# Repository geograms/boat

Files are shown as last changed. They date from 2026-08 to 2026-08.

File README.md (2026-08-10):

# Boat-Home — Road-Towable Solar Trimaran

A 7.2 m Dutch-barge-style boat-home that is **its own trailer**: the
stabiliser floats fold underneath the hull and carry six driven wheels,
so one Mercedes-Viano-class car tows it on German roads and it drives
itself in and out of the water on a slipway. Solar-electric, weed-proof
waterjets, and a walk-on glass sun deck — you stand on the glass, the
panels live safely underneath it.

Parametric CAD in FreeCAD (Python-scripted); every legal, structural
and hydrostatic constraint is asserted in code, so a dimension cannot
drift without the build failing.

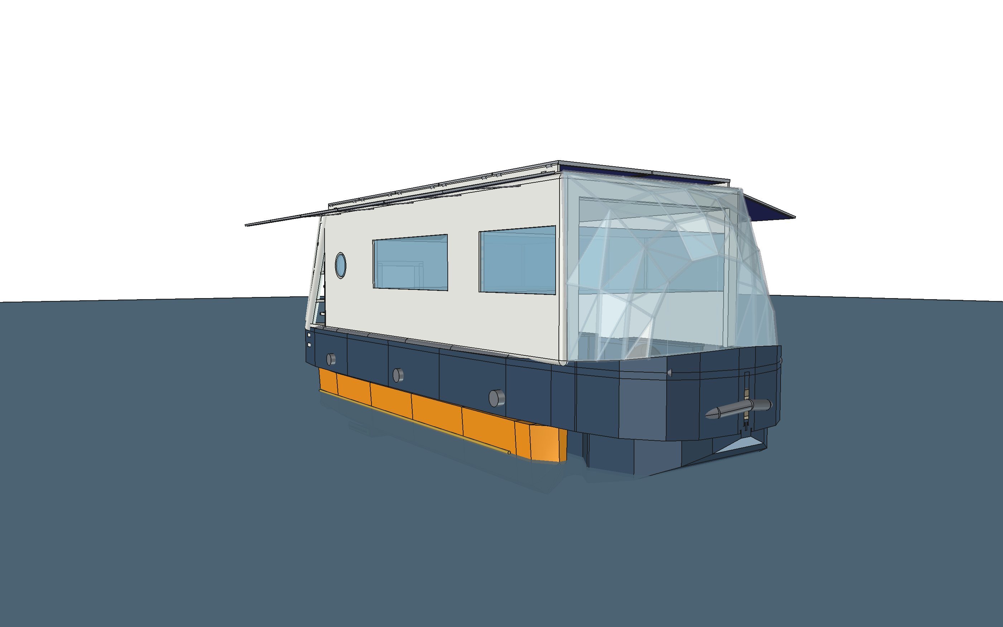
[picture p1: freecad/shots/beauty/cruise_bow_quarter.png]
cruise


---

## 1. Principal dimensions

| | |
|---|---|
| Length over hull | **7 200 mm** |
| Length with drawbar out | **9 094 mm** |
| Beam, hull | **2 500 mm** |
| Beam, road (folded) | **2 535 mm** (StVZO limit 2 550) |
| Beam, afloat (floats out) | **4 716 mm** |
| Height on the road | **3 002 mm** (limit 4 000) |
| Air draft afloat | **2 260 mm** |
| Draft | **279 mm** empty, **299 mm** loaded (hull carries the boat only) |
| Freeboard, loaded | 851 mm |
| Mass, boat alone | **2 228 kg** empty (the hangar floats itself) |
| Mass, hangar | **901 kg** — a complete trailer |
| Mass, combination | **3 429 kg** with crew and stores |
| Road category | **O2 trailer, ≤ 3 500 kg** — 252 kg of margin loaded |
| Ground clearance, road | 482 mm |
| Track / wheelbase | 1 820 / 3 300 mm |
| Coupling height / tongue load | 445 mm / +100 kg |

### Living quarters

| | |
|---|---|
| Cabin | 5 300 × 2 280 mm inside |
| Headroom | **1 850 mm** clear over the sole |
| Floor area | 12.1 m² |
| Berths | **5** — athwartships double, bunk (2), single settee, dinette double |
| Heads | 1 400 × 900 wetroom with shower |
| Galley | induction hob, sink, washer-dryer, full-height fridge/freezer |
| Fresh water | 200 L in a bilge tank under the sole |
| Glazing | 2 picture windows per side, 1 800 × 600 and 1 200 × 600 |
| Sky dome | glass room forward, **no wall** — 2 040 mm portal, sole continuous, 2 050 mm head |

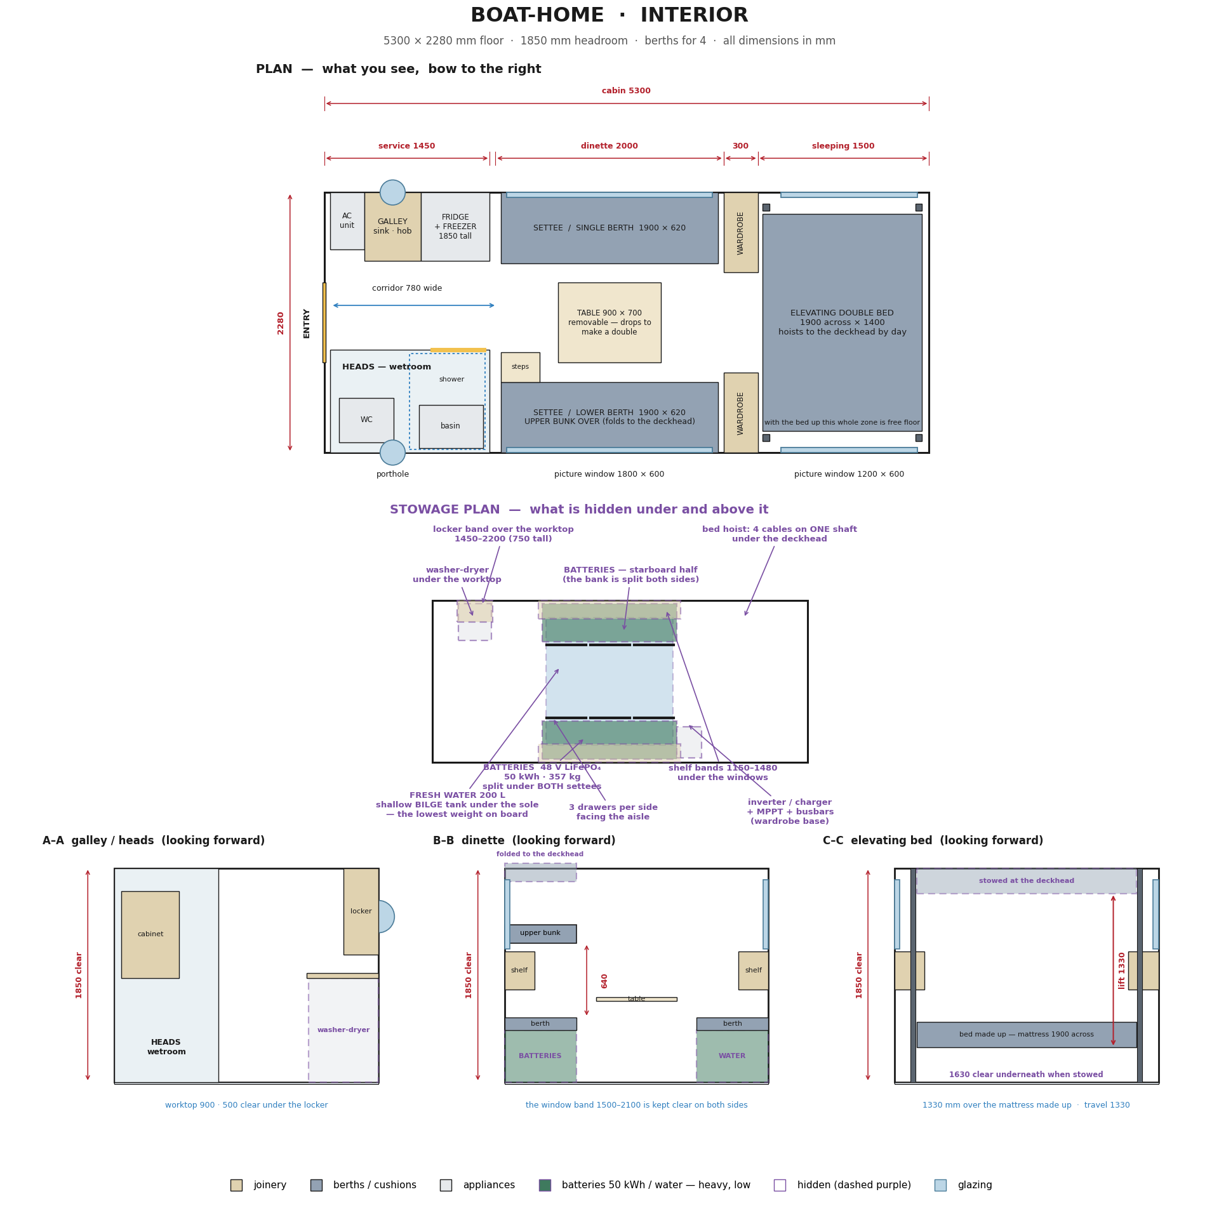
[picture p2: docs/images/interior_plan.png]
interior


---

## 2. Performance

**Installed power: 3 × 2 kW flush-intake waterjets = 6 kW.** Estimates
from an ITTC friction line plus a residuary factor for a blunt barge
hull; wetted surface 28.0 m² in trimaran trim, **3 582 kg all-up — the
computed mass, wired to `params.mass_budget()`**, waterjet propulsive
efficiency 0.45. Method in
[docs/performance.md](docs/performance.md).

| Speed | Shaft power | Range on 45 kWh usable | Endurance |
|---|---|---|---|
| 2.0 kn | 0.18 kW | **488 NM** | 244 h |
| 3.0 kn | 0.58 kW | **233 NM** | 78 h |
| 3.5 kn | 1.03 kW | **153 NM** | 44 h |
| 4.0 kn | 2.15 kW | **84 NM** | 21 h |
| 4.5 kn | 4.37 kW | **46 NM** | 10 h |
| **4.7 kn max** | 6.0 kW | 32 NM | 7 h |

**Maximum ≈ 4.7 knots**, power-limited rather than hull-speed-limited
(theoretical hull speed is 6.2 kn, needing 30 kW). The last 0.2 kn costs as much power
as the first 4 — this is a boat to cruise at 3–4 kn, not to push.

**Solar-neutral cruising.** With 4.60 kWp and ≈ 24 kWh on a good summer
day, eight hours at **4.2 knots** is solar-neutral: the boat moves all day
and finishes with a fuller battery than it started. In spring or autumn
(12 kWh) that falls to 3.6 kn, and on an overcast winter day (6 kWh) to
2.7 kn.

| | |
|---|---|
| Battery | 48 V LiFePO₄, **50 kWh**, 357 kg, split under both settees |
| Structure | foam-core GRP sandwich, 103 m² of panel, **754 kg** |
| Solar | **4.60 kWp** — 10 × 230 W flexible on the roof, 10 more as side curtains (4.14 kWp effective; one panel type for the whole boat) |
| House load | ≈ 2.5 kWh/day (fridge, lights, water, AC standby) |
| Steering | differential thrust, no rudder |
| On land | ≤ 10 km/h under its own wheels; towed at road speeds |

---

## 3. The five configurations

Photo-reference renders — perspective camera, natural eye heights,
interior hidden and glazing closed so nothing reads as a cutaway — live
in `freecad/shots/beauty/`: five viewpoints per mode (bow quarter,
stern quarter, beam on, from above, low from the water), 2 800 × 1 750.
They are the plates at the front of the PDF gallery.

| Mode | What it is | Renders |
|---|---|---|
| `road` | floats folded under the hull, balconies up over the windows, towed stern-first | [bow qtr](freecad/shots/beauty/road_bow_quarter.png) · [stern qtr](freecad/shots/beauty/road_stern_quarter.png) · [beam](freecad/shots/beauty/road_beam.png) · [above](freecad/shots/beauty/road_drone.png) · [low](freecad/shots/beauty/road_low.png) |
| `launch` | driving itself down the slipway on six wheels | [bow qtr](freecad/shots/beauty/launch_bow_quarter.png) · [stern qtr](freecad/shots/beauty/launch_stern_quarter.png) · [beam](freecad/shots/beauty/launch_beam.png) · [above](freecad/shots/beauty/launch_drone.png) · [low](freecad/shots/beauty/launch_low.png) |
| `harbor` | jack-up: floats carry the boat, keel awash, tyres as rolling quay fenders | [bow qtr](freecad/shots/beauty/harbor_bow_quarter.png) · [stern qtr](freecad/shots/beauty/harbor_stern_quarter.png) · [beam](freecad/shots/beauty/harbor_beam.png) · [above](freecad/shots/beauty/harbor_drone.png) · [low](freecad/shots/beauty/harbor_low.png) |
| `cruise` | trimaran, floats out, balconies down | [bow qtr](freecad/shots/beauty/cruise_bow_quarter.png) · [stern qtr](freecad/shots/beauty/cruise_stern_quarter.png) · [beam](freecad/shots/beauty/cruise_beam.png) · [above](freecad/shots/beauty/cruise_drone.png) · [low](freecad/shots/beauty/cruise_low.png) |
| `anchor` | at anchor, held by the stern anchor | [bow qtr](freecad/shots/beauty/anchor_bow_quarter.png) · [stern qtr](freecad/shots/beauty/anchor_stern_quarter.png) · [beam](freecad/shots/beauty/anchor_beam.png) · [above](freecad/shots/beauty/anchor_drone.png) · [low](freecad/shots/beauty/anchor_low.png) |

cruise, bow quarter

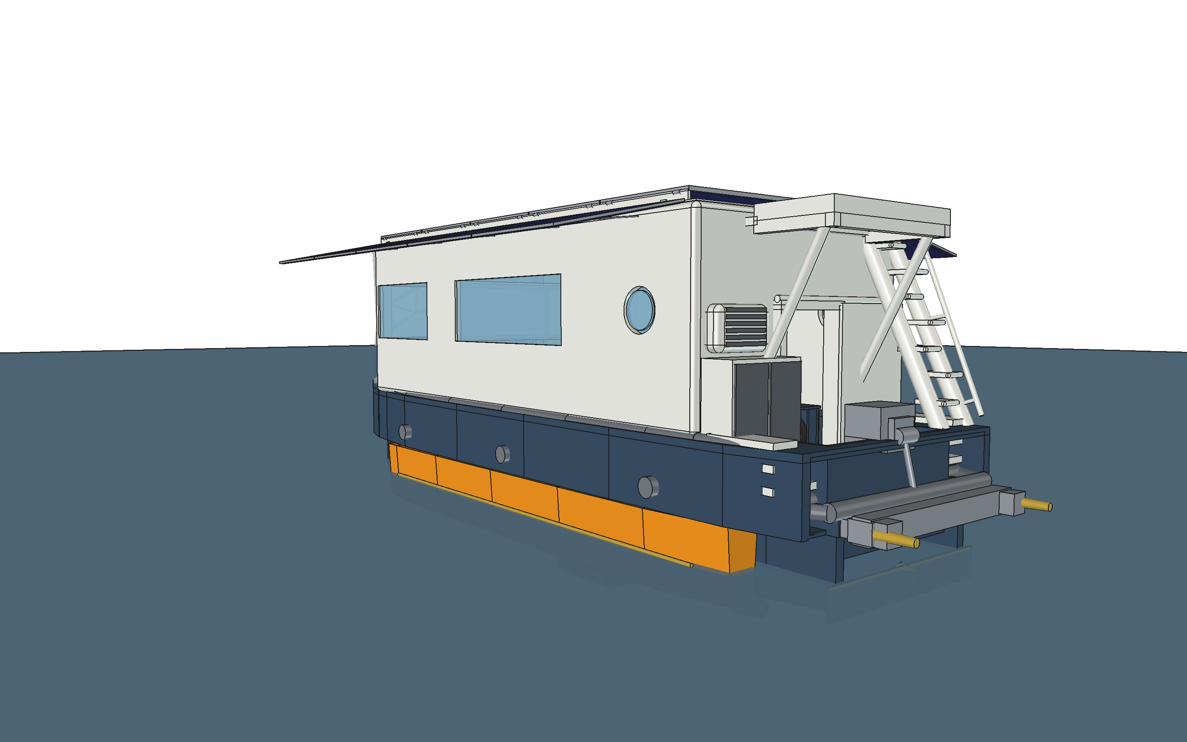
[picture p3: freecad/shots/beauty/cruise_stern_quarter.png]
cruise, stern quarter


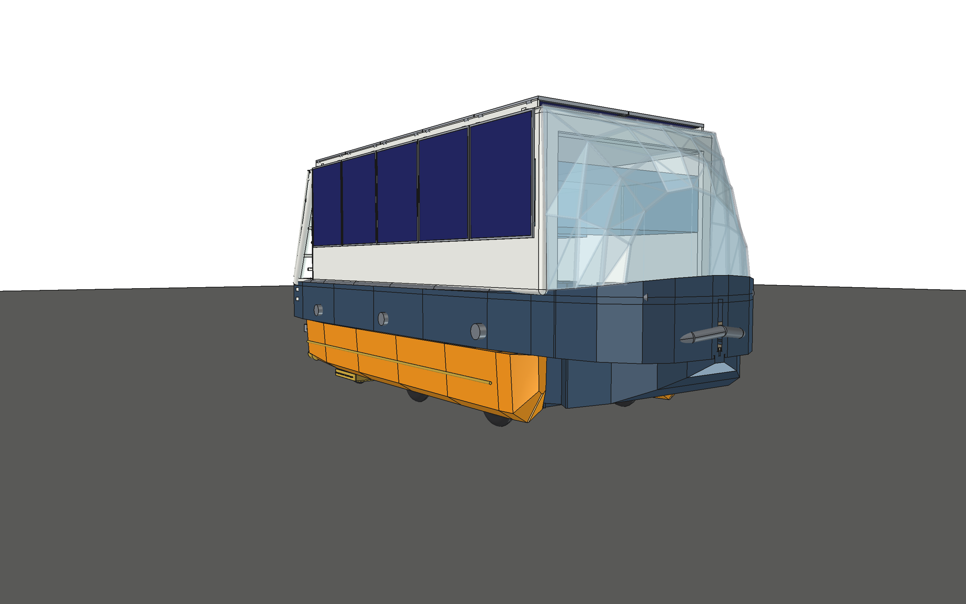
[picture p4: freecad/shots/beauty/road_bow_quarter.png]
road, bow quarter


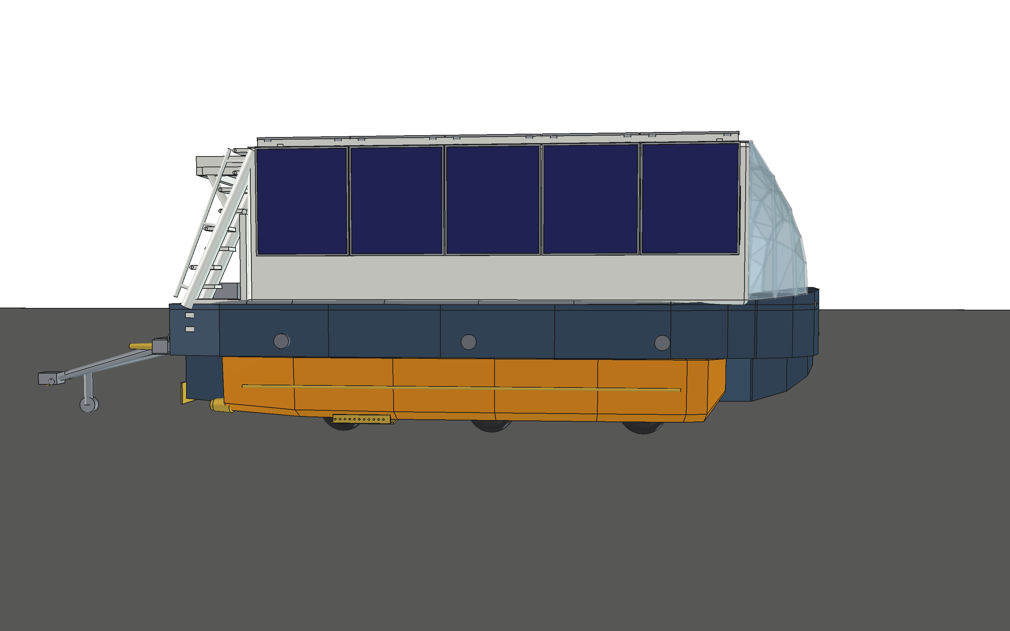
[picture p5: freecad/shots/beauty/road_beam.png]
road, beam on


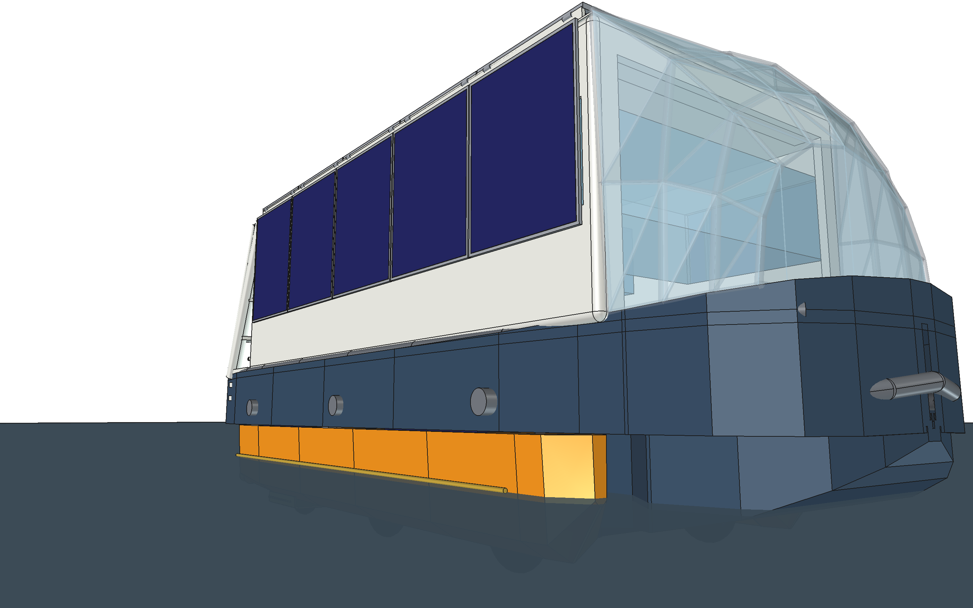
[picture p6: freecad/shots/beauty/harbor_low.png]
harbour, low from the water


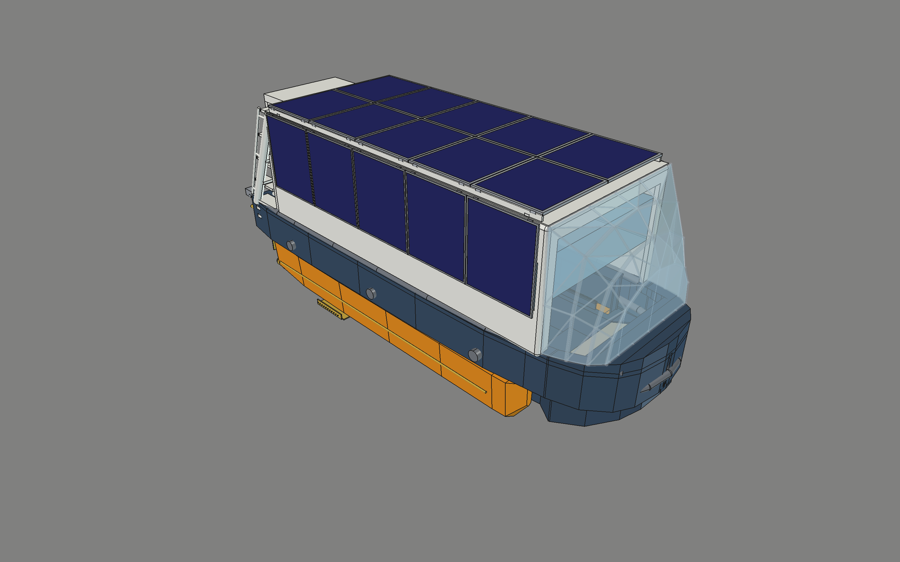
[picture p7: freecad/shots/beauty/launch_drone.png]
launch, from above


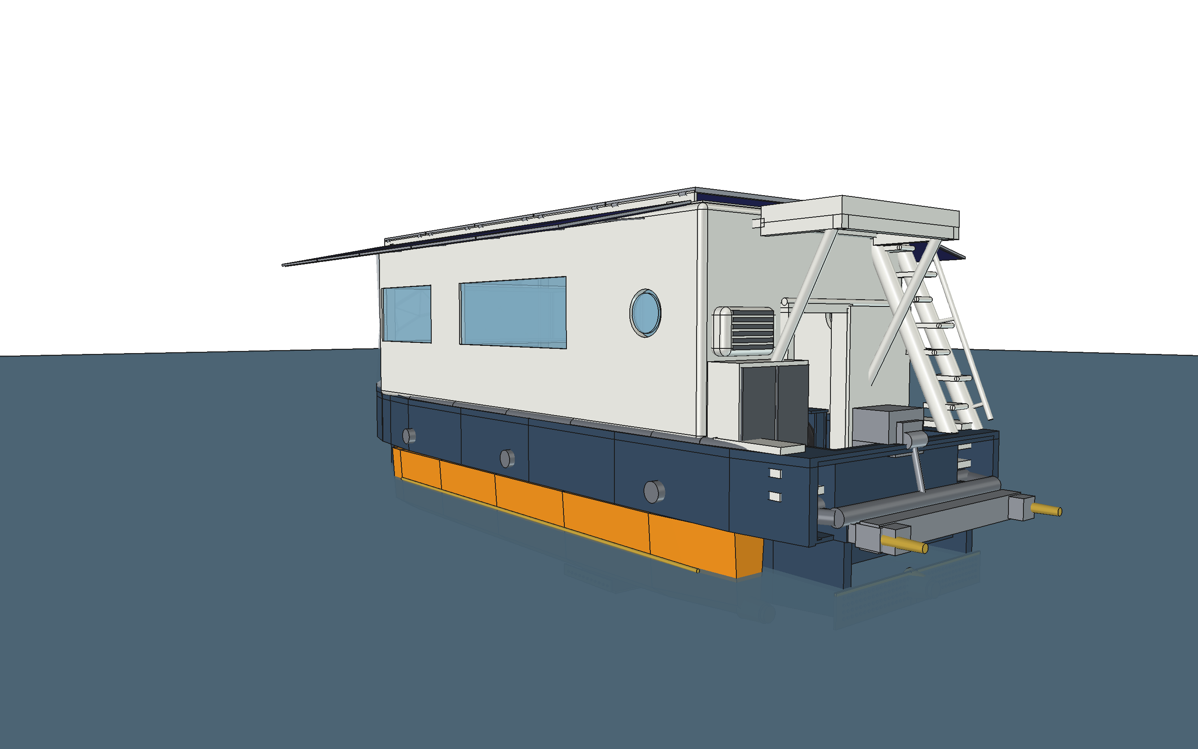
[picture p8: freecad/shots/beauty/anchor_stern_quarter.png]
anchor, stern quarter


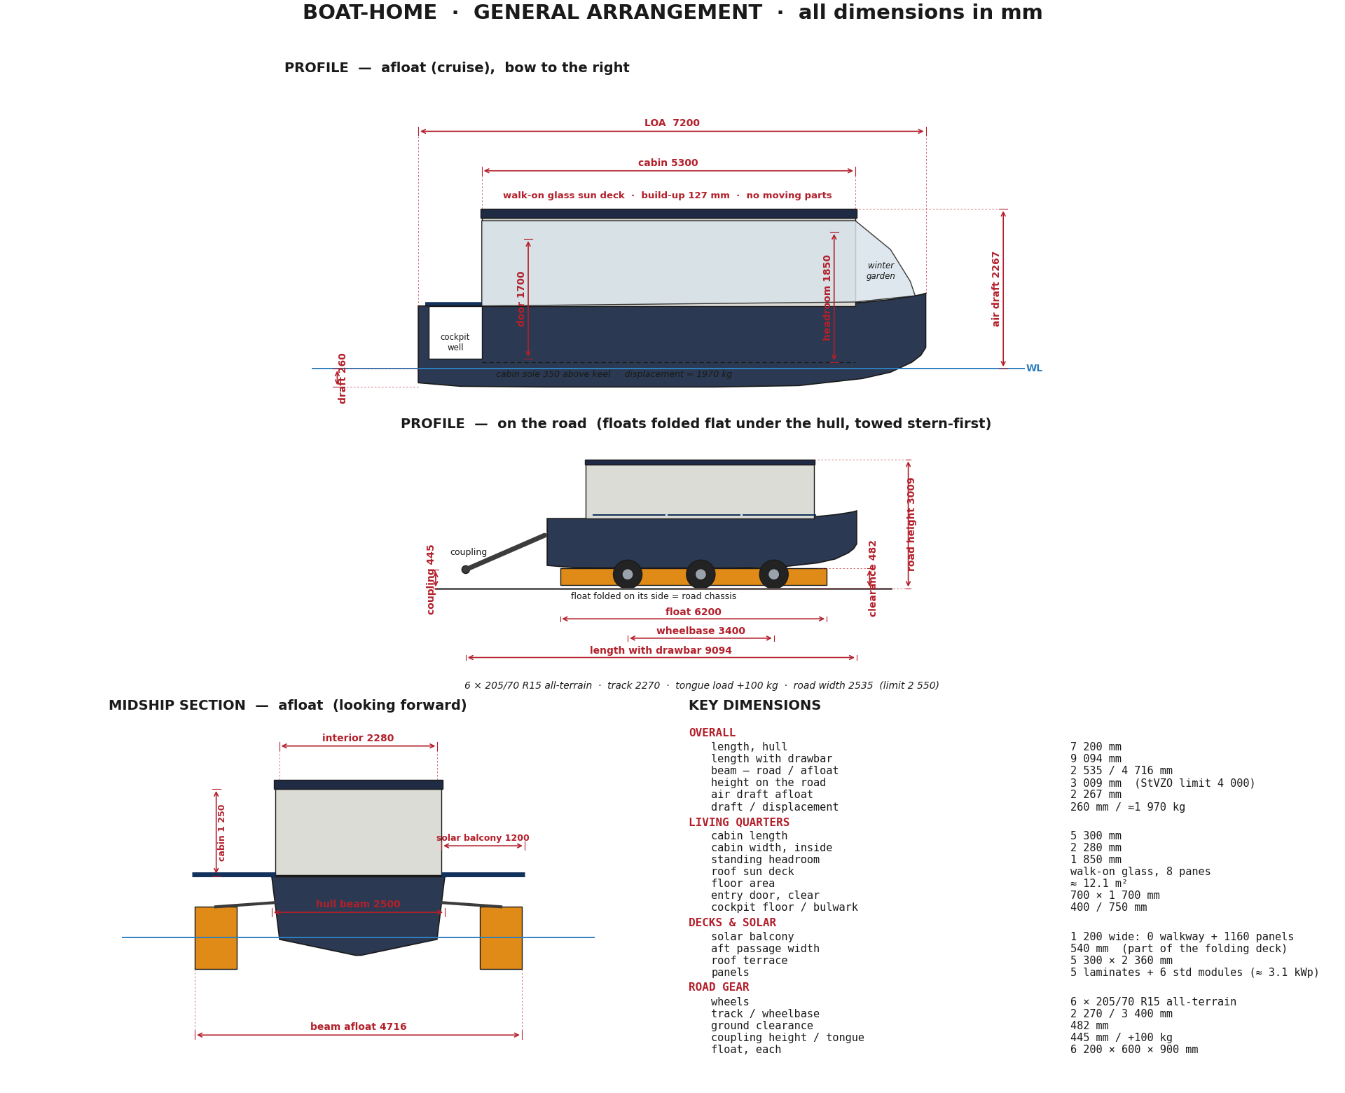
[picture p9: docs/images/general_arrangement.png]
general arrangement


---

## 4. Key systems

**Detachable hangar** — the running gear is a **separate vehicle**: two
spine beams along the hull sides carrying the four arm shoulders, joined
aft of the transom by a bight that carries the drawbar. It couples on the
water — cone guides, then four 24 V worm bayonet locks — and detached it
is a **4.7 m catamaran dinghy** with a motor in each float. The point is
certification: the hangar is the trailer, **the boat is cargo**.
→ [docs/hangar.md](docs/hangar.md)

**Running gear** — one rigid welded arm per station, a single
shoulder pin, 90° swing. Road: float on its side flush under the hull,
wheels vertical. Water: float flat, wheels dry above the waterline. Six
155/70 R12C trailer wheels on swing arms, electric-over-hydraulic drive with the
machinery sealed inside the floats. → [docs/wheels.md](docs/wheels.md)

**Stability** — the stem alone has **GM −0.43 m**: the floats are not a
stability aid, they *are* the stability. Extending them takes GM from
1.20 to **4.59 m** and peak righting from 3.8 to **14.8 kNm** — nearly
**4 ×** — and beam from 2.48 to **4.02 m**. The curve peaks at 16° and
saturates there: the float has 205 mm of freeboard. What actually
limits the boat in a blow is windage, not the floats: stand the solar
rails up in a Beaufort 6 gust and the margin falls to 1.12.
→ [docs/stability.md](docs/stability.md)

**Propulsion** — flush perforated intake grids on the float sides below
the waterline (0.5 m/s face velocity, 14 mm holes, so weed drifts past),
internal duct to an enclosed pump, tail nozzle. Nothing rotating is
reachable by weed. → [docs/propulsion.md](docs/propulsion.md)

**Exoskeleton** — an external steel ladder-loop frame carries every
point load (arms, balconies, tow, fenders); nothing structural crosses
the living volume. → [docs/structure.md](docs/structure.md)

**Construction** — primary structure is **foam-core GRP sandwich**: PVC
and PET core, biaxial E-glass skins, epoxy, vacuum bagged, panels laid
up flat on a table and CNC-cut from the model. **103 m² of panel,
754 kg** — computed from measured areas × the laminate schedule, not
estimated. The middle 3.6 m of the hull is exactly developable, so it
needs no jig at all. → [docs/construction.md](docs/construction.md)

**Roof deck** — the solar panels **are** the guardrail. Two continuous
rows of five 230 W flexible laminates in alu frames hinge on the deck
edges: flat they cover the roof and harvest **2.30 kWp**, rotated up
they stand as a **1 234 mm barrier** and leave the whole 12.7 m² deck
free to walk on. No glass, one hinge and one catch per panel. It
replaced a walk-on glass deck that weighed 460 kg with **155 kg** — and
that deck had no guardrail at all.
→ [docs/roof.md](docs/roof.md)

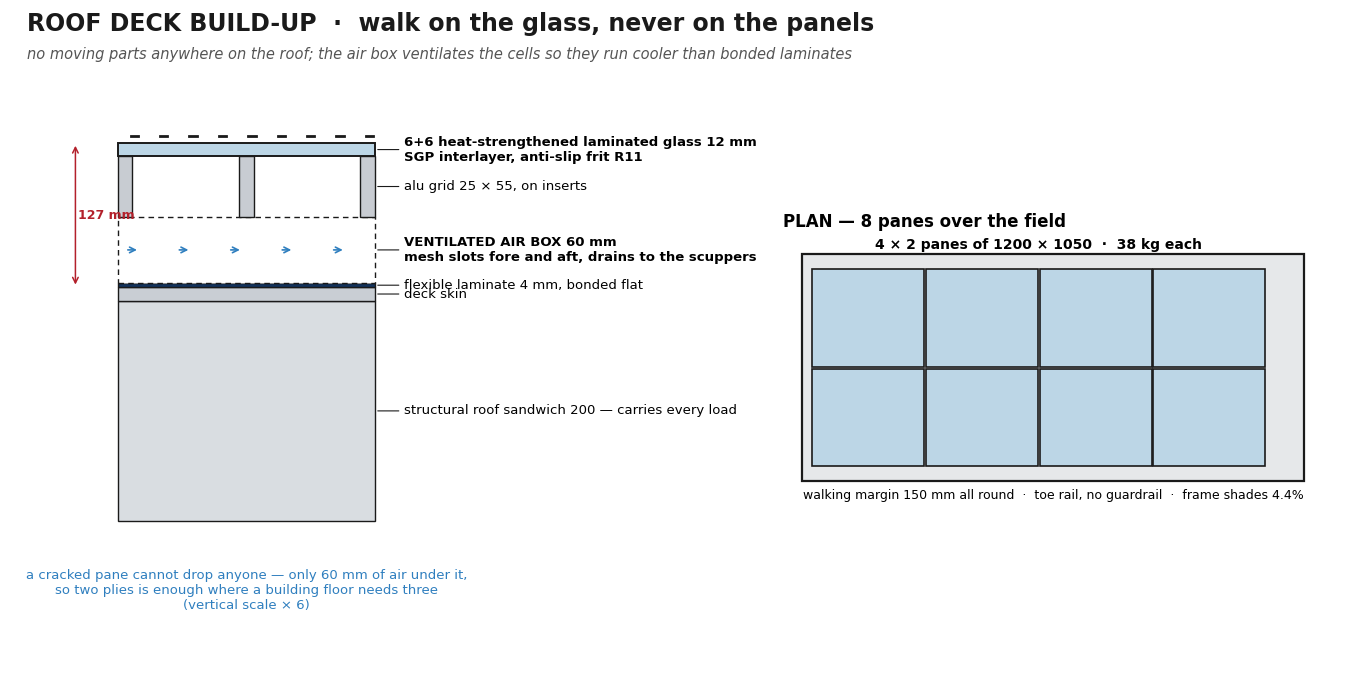
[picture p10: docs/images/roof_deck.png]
roof deck


**Solar curtains** — the balconies are gone. The same panel as the roof
rails, five a side, hinged on the roof-to-wall corner: closed they cover
the windows and slim the boat for the road, at 78° they project 1 129 mm
out as an awning over the glass. 2.30 kWp for **117 kg**, where the
walkable balconies were ~298 kg of frame and mechanism.
→ [docs/roof.md](docs/roof.md)

**Interior** — heads, galley, dinette that sleeps two, elevating double
bed forward, fold-down bunk to port; batteries and water low and
amidships. → [docs/interior.md](docs/interior.md)

**Front sky dome** — a glazed conservatory over the foredeck: half a
dome cut flat by the deck, so the deck is its floor and you walk into
it from the saloon — **no wall**, a 2 040 mm portal and the sole runs
straight through, 2 050 mm of headroom. Its aft rim lands exactly on
the living-quarters box corners. **51 flat panes**, all flat to
0.00 mm, on 8 meridians and **two ⌀48 tube purlins**: flat glass means
any pane can be re-cut anywhere.
→ [docs/dome.md](docs/dome.md)

**Tow and stern gear** — a wide A-arch on the transom pin-locks into a
sea gantry or an extensible drawbar; the 2 t electric self-recovery
winch and the anchor share the centreline so a ramp pull has no yaw
bias.

---

## 5. Cost estimate (2026, EUR, materials)

| Item | Low | High | Source |
|---|---|---|---|
| Foam core, PVC + PET, by zone | 3 800 | 5 200 | [hangar.md](docs/hangar.md) | detachable U-frame: coupling, electric locks, dinghy mode |
| [construction.md](docs/construction.md) |
| Glass fabric, biax NCF, roll quantities | 2 200 | 3 000 | 203 kg dry |
| Epoxy resin, hardener, fillers | 4 500 | 6 500 | 248 kg mixed |
| Vacuum consumables | 1 200 | 2 000 | €10–20/m² per shot |
| Fairing compound, primer | 900 | 1 500 | 400 h of it |
| Tooling: pump, table, extraction, PPE | 1 500 | 2 500 | one-off |
| Exoskeleton frame + tow arch | 2 600 | 3 200 | [structure.md](docs/structure.md) |
| Wheels, hubs, in-float drive | 5 600 | 6 500 | [wheels.md](docs/wheels.md) |
| Propulsion, 3 × 2 kW waterjets | 8 800 | 13 300 | [propulsion.md](docs/propulsion.md) |
| Roof deck: 10 flexible panels, alu frames, hinges | 2 900 | 3 400 | [roof.md](docs/roof.md) |
| Solar balconies | 1 700 | 2 000 | [roof.md](docs/roof.md) |
| Battery bank, 50 kWh LiFePO₄ | 9 000 | 11 000 | at 180–220 €/kWh |
| Electrics: inverter/charger, MPPT, switchgear, cabling | 3 000 | 4 500 | est. |
| Glazing: front sky dome + windows | 6 000 | 9 000 | [dome.md](docs/dome.md) |
| Interior fit-out incl. appliances, heads, AC | 12 000 | 16 000 | est. |
| Paint, antifoul, deck finish | 2 000 | 3 000 | est. |
| Approvals: national individual approval + engineering evidence | 3 000 | 12 000 | [hangar.md](docs/hangar.md) | detachable U-frame: coupling, electric locks, dinghy mode |
| [construction.md](docs/construction.md) | foam-core GRP: panel schedule, build sequence, shop, suppliers |
| [weight.md](docs/weight.md) | the mass problem and the 600 kg package that fixes it |
| [homologation.md](docs/homologation.md) |
| **Materials total** | **70 090** | **103 900** | |

Composite is **not cheaper on the materials line** — it is slightly
dearer than steel plate. What it removes is the fabricator's invoice,
the welding qualification and the shop equipment for a trade you would
otherwise have to learn.

**Built professionally**, add labour: ≈ 3 100 h at 60–80 €/h =
**186 000–248 000**, so a yard-built boat lands near
**260 000–360 000**. The design assumes a self-build, where that labour
is your own time — or a **split build**, which is what the yard
conversation is about: yard does hull and float panels, owner does
fit-out.

---

## 6. Build time

| Phase | Hours |
|---|---|
| Panel layup and post-cure | 250 |
| Hull and float assembly, taping, filleting | 350 |
| Fairing and coating | 400 |
| Floats, arms, wheels, hangar kinematics | 350 |
| Propulsion install and ducting | 150 |
| Roof deck, glass, solar, wiring | 200 |
| Interior joinery and fit-out | 500 |
| Electrics, plumbing, systems | 250 |
| Commissioning, trials, approvals | 150 |
| **Total** | **≈ 3 100 h** |

- **Self-build at 15 h/week** — ≈ 4 years
- **Self-build at 25 h/week** — ≈ 2.4 years
- **Professional yard, 2–3 people** — ≈ 8–11 months elapsed
- **Split build** — yard laminates and assembles the shell (≈ 1 000 h),
  owner does fit-out (≈ 2 100 h)

---

## 7. Open risks

1. **Mass: legal, but the design figure is stale.** Computed from
   measured areas × the laminate schedule plus every known fitting:
   **2 957 kg empty, 3 257 kg with crew and stores** — inside the
   3 500 kg category O2 trailer limit with 243 kg of margin, after the
   solar guardrails took 305 kg off the roof and the dome glass another
   20. `checks()` still fails against the inherited **2 000 kg** design
   figure, which predates the computed budget: it wants re-baselining or
   another 900 kg, and quietly raising it is not an option.
   The **jack-up stance** is the live one: floats give 4 152 kg, 1.27 ×
   the loaded mass where 1.40 is wanted, so the keel will not ride
   awash. That wants float *depth*, not weight — 150 mm deeper floats
   give 1.51 × inside the road-height limit.
   → [weight.md](docs/weight.md)
2. **Road beam tolerance.** 2 535 mm nominal against a 2 550 mm limit is
   **7.5 mm per side**, and a hand-laid laminate plus a fair coat eats
   5 mm of it. `checks()` now asserts the as-built beam. This is the
   most likely way the boat becomes road-illegal *after* it is built,
   and it is far cheaper to fix in `params.py` than in a mould.
3. **Fairing labour.** 400 h is the estimate for hull plus two floats.
   It is the item most likely to overrun and the one that stalls owner
   builds in year two.
4. **Workshop conditioning.** Epoxy needs 18–25 °C and stable humidity
   through two German winters — an enclosed heated space, not a tent,
   plus extraction and P3 protection for grinding cured glass.
5. **Road approval.** The folding running gear is not the problem — the
   **brake** is. Over 750 kg an overrun brake to UN R13 is mandatory and
   approvals go to catalogue axle/brake combinations, which swinging
   arms with hydraulic hub drive do not have. Cap the land drive at
   6 km/h so the vehicle stays a trailer.
   → [homologation.md](docs/homologation.md)
6. **Jet hydrodynamics** are first-order estimates — the intake grids
   want CFD or a tank test before committing.
7. **Arm and shoulder-pin fatigue** — each arm carries ~1 000 kg through
   one pin, cycled every launch.
8. **Float compartmentation is not modelled.** The floats hold the drive
   machinery *and* the reserve buoyancy. Three watertight cells per
   float is cheap now and impossible later.
   → [construction.md §8](docs/construction.md)

---

## 8. Road approval — the hangar as a trailer

Full research, sources and cost bands: [homologation.md](docs/homologation.md).

The running gear is part of the boat, so what gets registered is the
whole thing as a **category O2 trailer** (750–3 500 kg). Three findings
shape the design:

1. **Keep the land drive at ≤ 6 km/h.** German registration law applies
   to motor vehicles over 6 km/h; at or below it the wheel drive is a
   manoeuvring aid and the vehicle stays a *trailer*. Above it, the
   thing becomes an amphibious motor vehicle — a far harder approval,
   with an unresolved conflict between road and waterway marking. The
   Sealander swimming caravan is registered as a caravan and a
   category D motorboat precisely *because* it has no drive of its own.
   The design currently says 10 km/h; **6 is worth more than the 4.**
2. **The brake is the obstacle, not the folding gear.** Over 750 kg an
   overrun brake to UN R13 is mandatory, and approvals are granted to a
   *catalogue combination* of overrun device, axle and brake. Design
   the arms around a **hydraulic overrun boat-trailer brake set** and
   the paperwork comes free with the parts; invent a brake and it is a
   five-figure test programme.
3. **There is no EU-wide route.** EU individual approval covers only M1
   and N1, so a trailer gets a *national* individual approval, valid in
   the issuing state; other states "shall permit" it unless they doubt
   equivalence (Art. 46, Reg. 2018/858). **Register where you live** —
   Germany requires re-registration within 12 months of a resident
   bringing a vehicle in.

| Country | Fees + engineering | Elapsed | Notes |
|---|---|---|---|
| **Germany** — § 21 StVZO / § 13 EG-FGV | **≈ 3 000–12 000** | 4–10 months | inspector-led; a plain self-built trailer goes through for ≈ €430, and that is the floor |
| **Portugal** — IMT homologação individual | **≈ 1 700–6 500** | 4–12 weeks | document-led; €160 homologation + €45 matrícula, but IMT may demand accredited lab tests |
| **Netherlands** — RDW individual approval | ≈ 250–300 in fees | weeks | the most transparent price list in the EU |

**Next step, before more CAD:** buy a €300–800 pre-assessment from a
technical service and get the required evidence in writing.

---

## 9. Documents

| Document | Covers |
|---|---|
| [performance.md](docs/performance.md) | speed, range, the resistance model |
| [wheels.md](docs/wheels.md) | hangar kinematics, in-float drive, BOM |
| [propulsion.md](docs/propulsion.md) | waterjets, weed strategy, BOM |
| [structure.md](docs/structure.md) | exoskeleton frame, tow arch, stern gear |
| [roof.md](docs/roof.md) | solar guardrails, the deck, the balconies |
| [homologation.md](docs/homologation.md) | road approval: trailer vs amphibian, brakes, DE/PT/NL cost and time |
| [dome.md](docs/dome.md) | front sky dome: flat glazing, the two tubes, the open portal |
| [interior.md](docs/interior.md) | layout, stowage, services, mass budget |
| [aft_entry.md](docs/aft_entry.md) | companionway, porch, ladder, AC, lockers |
| [glossary.md](docs/glossary.md) | vocabulary for every part and term |

---

## 10. Repository layout

```
freecad/            the model — the source of truth
  params.py         ALL dimensions, kinematics, checks() asserts
  build_boat.py     geometry builders -> boat_<mode>.FCStd
  view.sh           build + open in the FreeCAD GUI
  beauty_shots.py   perspective photo-reference renders -> shots/beauty/
  ga_drawing.py     dimensioned general-arrangement sheet
  interior_plan.py  interior sheet: plan + stowage plan + sections
  roof_cards.py     roof-deck spec cards
  shots/beauty/     the renders (perspective, exterior, never stale)
docs/
  *.md              per-system design studies (table above)
  images/           dimensioned spec cards and drawings
  make_pdf.py       renders this README to docs/boat-home.pdf
drafts/             original concept PDF + STL sketch
*.scad, Makefile    legacy OpenSCAD sketch (superseded)
```

## 11. Working on it

```sh
./freecad/view.sh                              # open in the GUI
~/bin/FreeCAD.AppImage freecad/beauty_shots.py # regenerate all renders
python3 freecad/ga_drawing.py                  # arrangement sheet
python3 freecad/interior_plan.py               # interior sheet
python3 freecad/roof_cards.py                  # roof spec cards
python3 docs/make_pdf.py                       # this README as a PDF
python3 -c "import sys; sys.path.insert(0,'freecad'); import params; params.checks()"
```

`params.py` is the single source of truth. `checks()` recomputes road
legality (StVZO), submergence margins, stability, glass thickness, panel
fit and interior clearances from the same numbers the geometry uses —
change a dimension and the asserts tell you what broke.

---

© 2026 Max Brito. All rights reserved.
Contact: [maxbrito@pm.me](mailto:maxbrito@pm.me)

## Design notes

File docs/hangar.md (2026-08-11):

# The T-Hull and the Nesting Floats

Status: design study. Geometry in `freecad/params.py` (`STEM_HW`,
`T_STEP_Z`, `POD_DOCKED`, `POD_SEA`, `arm_points()`), shapes in
`build_boat.py`, limits asserted in `checks()`.

## 1. The T

Aft of the bow the hull's underwater body narrows to a central **stem**
(the stroke of the T); the deck and cabin keep the full 2 500 mm beam
(the bar), and so does the **bow — the head of the ship is full width
to the waterline** for stability forward. The two notches beside the
stem are where the floats live: **same level as the hull, bottoms
flush**, so the docked boat is one clean barge body.

```
FRONT VIEW                DOCKED                    EXTENDED (sea)

 ┌───────────────┐   ┌───────────────┐         ┌───────────────┐
 │     cabin     │   │     cabin     │         │     cabin     │
 ╞═══════════════╡   ╞═══════════════╡         ╞═══════════════╡
 │   ┌───────┐   │   │╔══╗┌────┐╔══╗│  ~WL~   │    ┌────┐     │ ~WL~
 │   │ stem  │   │   │║FL║│stem│║FL║│     ╔══╗│    │stem│    │╔══╗
 └───┴───────┴───┘   └╨──╨┴────┴╨──╨┘     ╚══╝└────┴────┴────┘╚══╝
                      flat bottom flush    sliders push them 0.7 m out
```

| | |
|---|---|
| Stem | **1 560 mm** beam below z 600 — floats the boat alone, and swallows the retracted beams |
| Floats | **5 400 × 460 × 700**; bottom 110 mm below the keel, top under the wing; noses protected by 1 200 mm of solid bow |
| Docked | outer faces flush at 2 500; draft 313 mm loaded |
| Extended | **771 mm** out on the V arms — GM 1.20 → 4.59 m, peak righting 3.8 → 14.8 kNm |
| Dinghy | both floats + bight: 6.1 m beam, 216 mm freeboard with two aboard |

## 2. Docking — screw the frame down, afloat

No slipway, no winching against buoyancy. **A rotating electric screw
sits in each V arm, between the float and the frame.** The floats stay
where the water puts them; the screws drive the **frame** up and down
relative to them.

| Setting | Frame drop | What it is for |
|---|---|---|
| up | 0 | towing, and carrying the boat |
| **dock** | **334 mm** | channel and girders line up exactly |
| under | 700 mm | frame **174 mm below the water** — it passes under a floating boat with nothing to catch |

**Why this and not the two attempts before it.** Afloat the boat's
channel sits **188 mm** above the water and the hangar's girders
**526 mm** above its own, so the frame has to come down **334 mm**.

- *Winch it down:* 1 703 kg of buoyancy on a cable, 851 kg even through
  a 2:1 purchase. Doable, but it fights the boat every time.
- *Slipway:* needs a slipway. There isn't one in the plan.
- *Screws:* the same 334 mm, wound in, repeatable, and it stops
  wherever you leave it.

**4 screws, 700 mm of travel, 887 kg each** with the boat aboard —
the floats carry it through the arms, so the screws are in that load
path. Trapezoidal and self-locking, which makes them the **ride-height
adjustment** as well: set the boat's attitude on the frame and it stays
there with no power and no pin.

**No ramp is cut in the hull**, and two attempts proved why: at the
full 334 mm the channel has to be cut up to z 1 134 at the transom and
takes the stern bottom with it; at 120 mm the hull volume came out
*identical* with the cut and without it, because the channel is already
an open mouth at the transom. There was never anything to flare.

**The wheels stay dry throughout** — retracted, the tyre bottom is
222 mm above the boat's waterline and 555 mm above the hangar's own.

## 3. Extenders

**Two V arms per side** on vertical pins, 900 mm long, opening 59° to
put the float **771 mm out and parallel**. The water opens them; a
rope shuts them. No motor, no screw, no telescope. See
[floater.md](floater.md) §5.

## 4. Wheels — four, on the frame, on swing arms

They are no longer on the floats. See **[wheels.md](wheels.md)** for
the mechanism. In short: four **155/70 R12C** trailer wheels, each on
the end of a **445 mm arm** pivoted off the girder web, swinging 180°
between the road and a lined box in the **T-wing**. Track 1 820,
ground clearance 261, tyre stowed 310 mm above the waterline,
self-locking, workable afloat.

## 5. What it does to certification

The frame, the floats, the running gear and the drawbar unbolt as one
unit: that unit is **the trailer**, the boat is cargo on it. The
wheels never carry through the boat's structure - the load path stops
at the girder.

## 6. Open points

- **Dinghy freeboard is 216 mm** with two aboard — thin. Options: bigger
  floats stern-only, or accept it as a calm-water tender.
- The T-step at z 600 narrows the interior below that height: the sole
  band from z 350 to 600 is **1 560 mm** wide, not 2 280. The berths sit
  above z 600, but the heads floor and the tank bays need a layout pass.
- The stem quarters near the transom want fairing into the jets' inflow.
- Spike rail wear pads and the bayonet preload need detailing.

## 7. The floor, and why it is two parts

Asked for an aluminium bottom on the hangar that would both protect the
hull underneath and be a platform to walk on when undocked. It has to
be **two parts**, because one part cannot be in two places — and the
reason is worth writing down.

**The frame has no structure below the hull.** The girders sit at
y ±835, z 600 … 800 — *above* the stem and *outboard* of it. Every
route from there down to the keel is blocked:

| Route | Blocked by |
|---|---|
| straight down at y ±835 | the docked float, z −110…590, x 600 … 6 000 |
| inboard of that | the stem: 1 560 mm wide below z 600, and its face is at y 780 — the same y as the float's inner face, so there is **zero gap** to thread through |
| forward, past the float's bow | the hull goes full width from x 5 600 (half-width 1 081 at z 300) |

That leaves 720 mm of a 5 700 mm frame, at the stern, as the only place
a leg could reach the water. A 5 m cantilever off that is not
structure. And hanging the plate off the **floats** is out — they move.

So:

- **The deck** — **5.70 × 1.78 m**, the whole frame, in 3 mm 5083 tread
  plate on two panels with a centreline stringer and bearers, so
  neither panel cantilevers off its girder. **10.1 m²**, which roughly
  doubles the boat's own 12.7 m² of roof deck: detached and lying
  alongside, the hangar is a pontoon to work on, swim off, or park a
  boat's worth of gear on while the cabin stays a cabin. 760 mm above
  its own waterline. Docked it lifts out, because at z 800 between the
  girders is the inside of the boat. **134 kg** — plate is the whole
  cost of a deck, and this is the biggest single item on the hangar
  after the float shells.
- **The keel shoe** — 3 mm 5083 bolted flat on the stem's 1 560 mm
  bottom, transom to x 6 000. Sacrificial: it takes slipway rash,
  gravel and the odd rock. **81 kg**, and it belongs to the *boat*, not
  the hangar, which is the point — the hangar comes off and the
  protection stays.

## 8. Six wheels, a bow ramp, and what it can actually carry

**Six wheels.** A middle pair on the axle centroid at x 3 510. It halves
the girder spans — the longest bay goes 3 300 → 1 650 — and bending
goes as the span *squared*, so the girder that was right for two axles
came out at SF 8 with three. It drops to **60 × 120 × 4, 41 kg the
pair against 92**: the middle wheels pay for most of themselves. Each
wheel now carries **576 kg against a 900 kg tyre**.

It is not free. A third notch pair in each float costs **93 kg of
buoyancy** (185 → 278 kg a side), and buoyancy is what the hangar
floats and carries cargo on.

**The bow ramp.** 1 600 mm hinged on the frame's forward end,
projecting forward, lowering 25° to reach from the deck at z 800 down
to **z 124**. The forward tie is its hinge beam. *(First drawn hinged
1 600 mm back from there, which swung the ramp straight through that
tie — the bar was structural, and visible the moment the hangar was
rendered on its own.)*

### Could a car go up it?

**No.** Two independent limits, and buoyancy is the decisive one.

Stated as float freeboard, which is something you can look at, rather
than as a percentage of a buoyancy nobody can picture. Computed by
`params.payload_afloat()` and `params.float_freeboard()` — it used to
be this table alone, typed by hand against a hangar mass that had since
changed twice.

| Payload | Float freeboard |
|---|---|
| 300 kg | 207 mm |
| **400 kg** | **175 mm** |
| 500 kg | 144 mm |

The float pair displaces **1 600 kg** fully immersed. The hangar that
actually floats away is **781 kg** of that — not the 675 kg road
figure, because two of the three waterjets are built into the floats
and the arm jacks live in the V arms, so **106 kg was booked to the
boat that leaves with the hangar**. A car is 900–1 500 kg: it would put
the floats under before it was aboard.

And it would not fit anyway. Clear width between the girders is
**1 580 mm** and the deck overhangs to 1 760 — a Kei car's *track*
fits, its body does not — and the deck is 3 mm plate on ribs at
1 200 mm centres: right for people and cargo, not for 300 kg wheel
loads on a 200 mm contact patch.

**Afloat it will carry a quad, two motorbikes, or about 350 kg of
cargo** with sensible freeboard.

**On the road** it is a different question — as a trailer on its own
the O2 limit leaves 2 707 kg and the six tyres are good for 5 400 —
but the deck would need thicker plate and proper wheel tracks first.

### To actually carry a car

Float displacement would have to roughly double: **1 500 kg a side**
against 800 now. At 5.4 m long and 460 mm wide that means about
**1 200 mm of depth** instead of 700, which the wing underside will not
allow, so the float would have to grow in length and beam — and the
road width is already 2 500 of a 2 550 limit. It is a different boat,
not an option on this one.

## 10. The simplification pass — 766 → 675 kg

The hangar had grown a mechanism per problem and nobody could say what
it could carry. The reason was in the code, not in the concept:
**394 kg of its 766 kg came from hand-guessed constants** —
`MASS_HYDRAULICS` a flat 80, `ARM_KG` a flat 22, and a bare unnamed
`+ 20` on the end of the sum. Half the trailer's mass was an estimate
nobody had revisited, so the payload could only ever be a guess too.

### What actually came off

| | was | now | |
|---|---:|---:|---|
| Deck | 140.9 | **87.8** | plank instead of plate — see below |
| Drive | 80.0 | **54.0** | sized for sand, not for a ramp it cannot climb |
| Girders + diagonals | 54.7 | **48.9** | 60 × 120 × 4, plus the torsion fix |
| Wheels | 90.0 | **78.0** | 13 kg each; the hub is on the arm, not counted twice |
| Float decks | 33.9 | **23.9** | PET60: the stub axles it was specified for moved to the arm |
| Ties | 35.9 | **25.8** | real box sections instead of a solid × 0.15 "fill" |
| Locks | 10.4 | **5.2** | two are drawn; the other two were per a dead spike |
| **Brakes** | **0** | **34.0** | a bill that was never presented — over 750 kg an O2 trailer must have them |
| **Total** | **766.1** | **675.0** | |

Loaded road mass **3 457 kg — 42 kg under the 3 500 limit**, where it
was 49 kg over.

### The deck was the answer to "unrealistic to move"

It was two plates of 880 × 5 700 × 3 mm tread — **66 kg each** — and
because z 800 between the girders is the inside of the boat, they had
to be **lifted out by hand, afloat, over the boat, every time it
docked**. Nobody moves 66 kg off a pontoon.

It is now extruded interlocking pontoon plank, which self-spans
1 425 mm between three bearers, so the ribs *and* the centreline
stringer both disappear. **Fifty-eight boards of 1.1 kg.** You take the
deck up one plank at a time.

It also has a **stated load rating for the first time: 2.5 kPa.** The
old deck was never checked against any load at all, and failed that one
by 2.9× read as a one-way strip.

### Three things that were wrong, not just heavy

- **The girder fails in torsion.** A kerb strike lands at the contact
  patch, z −261, while the girder's shear centre is at z 660 — a
  921 mm lever, **7.8 kNm of pure torque** into a thin box. No section
  that fits the wing channel survives it. The fix is a load path, not a
  thicker wall: twelve diagonals tying each wheel bracket fore and aft
  to a deck bearer, 7.9 kg, and the torque becomes a couple. It is now
  `structure_calc` case 4.
- **The swing arms were sized against four wheels when there are six.**
  `structure_calc` divided by 4 with three stations, overstating every
  wheel's share by 50 %. Corrected, the arm passes at SF 3.3 on an 8 mm
  wall instead of 12.
- **The deck bearers were drawn outside the docked guard**, so with the
  boat aboard a beam stood at z 660–800 between the girders — inside
  the stem, which the comment directly above it says cannot happen.

### And the drive could never do its job

3 kW a side was sized to climb a 1:8 slipway: 4 979 N. Two driven
wheels carrying a third of the boat can only put **4 579 N** through
wet concrete before they spin. **It was sized for a job traction
forbids** — which is what the winch is for, and always was. Re-sized
for what it really does, soft ground at walking pace (sand at 12 %
rolling resistance, 4 120 N against 5 723 N of traction, 3 km/h), it is
2 kW a side.

## 11. Docking: the sequence, and proof that it fits

The hangar could never be shown to go under the boat, because nothing
in the repo ever tested it. Beauty shots cannot: the hull stands in
front of the hangar in every one, so a frame buried in the wing looks
perfectly fine. `freecad/dock_check.py` intersects the hull solid with
every part of the hangar and measures the volume that comes back.

**It found that the hangar overlapped the hull in every pose already** -
21 litres in cruise, 11 in road, 12 litres per float - none of it
visible in any render. The docking pose was not the problem; the model
had simply never been checked.

### The sequence

| | | |
|---|---|---|
| 1 | floats **splayed**, frame jacked **down 358 mm** | girders come to the boat's channel; the floats pass **outside** the hull instead of driving into the wing |
| 2 | winch forward | the girders enter the channels from astern; wheels are **down**, because stowed they stand up into a wing that has no pocket over them yet |
| 3 | jack the frame **up** | the boat's weight transfers to the floats, which sink ~356 mm **on their own** - the jack never has to push them down |
| 4 | close the V arms | the floats swing into their recesses, now at the right height |

Step 3 is why the stroke works. The float bottom goes from −166 mm
(hangar floating light) to −522 mm (fully docked); the recess floor it
has to reach is at −515. **It matches to 7 mm, and it is load transfer
that does it, not the screw.** The jack only travels the 358 mm of
step 1, leaving 342 mm of its 700 mm spare.

### What had to change to make it true

- **The wing's outer lip, `T_LIP_Z`, was the most expensive 40 mm in the
  model.** It is a *shadow line* - its only job is to let the docked
  float sit recessed behind the hull face. But everything that passes
  under the wing is capped by the **lip**, not by the step at 600: the
  float's top and the V arms were both drawn to 600 and were cutting
  through it along their whole length. Raising it 550 → 590 keeps a
  10 mm shadow line and gives back the float's full 700 mm of depth,
  its road clearance and its reserve.
- **The V-arm pins sat exactly on the stem face.** `py = sy * STEM_HW`
  put the pin, its lug, the open stop and the road latch half inside
  the hull. They belong on the groove's centreline - which is also the
  only line where the parallelogram closes without the float yawing.
- **The girder's web stiffeners were drawn 70 mm proud all round**, so
  eight of them stood outside a girder running in a 100 mm channel.
  A web stiffener in a box girder is an internal diaphragm.
- **The wheel pockets and the girder channel are one merged void**, and
  whichever was lined last left its wall standing in the other. The
  pocket's end walls were putting a plate through the girder twice per
  wheel.
- **There is no forward tie any more** and there cannot be one: at
  girder level it crosses the cabin (`SOLE_Z` 620 is 20 mm above the
  wing), and under the keel it cannot clear during the approach. Its
  job is done by the deck bearers when detached and by the boat itself
  when docked.
- **The float sat on the stem face with zero gap.** That is not a fit,
  it is a tangency; the check read 12 litres a side, which is 3 mm of
  numerical sliver over 3.8 m² of touching face. Nothing is built to
  zero.

Run it after any geometry change:

```bash
~/bin/FreeCAD.AppImage --console dock_check.py < /dev/null | tail -20
```

All eight poses now report **FITS**, zero interference.

## 12. The floats are fixed now, and what that decided

The V arms are gone. Each float bolts to the girder on **four welded
struts** - no pins, no stops, no haul ropes, no latch, no groove in the
float, no parallelogram to keep true, and no powered jacks either.
**Nothing on the hangar moves any more except the six wheels.**

| | was | now |
|---|---|---|
| Float connection | 4 swinging V arms on 8 vertical pins + 4 powered screw jacks | **4 welded struts** |
| Mass | 55 kg of arm gear + 56 kg of jacks | **36 kg** |
| Governing load | 16.4 kN of slam on a 900 mm lever, in bending | the same blow on a **260 mm** strut |

The strut is sized by a *side* blow, not the vertical one - 4.9 kN taken
as bending over its own short length, 12 MPa against 104. The axial
case is trivial. That is the structural argument for the change in one
line: **the arm multiplied the worst sea load by 3.5; the strut divides
it by the same.**

### What it cost, stated plainly

Righting is reserve × **lever**, and a fixed float can only sit where
the road lets it. Beam is 2.50 m in every condition instead of 4.05.

| | with arms | **fixed** |
|---|---|---|
| Peak righting | 14.7 kNm | **3.8 kNm** |
| F6 gust (4.0 kNm) | SF 3.7 | **SF 0.95** |
| Stability vanishes | beyond 40° | **~38°** |

**An F6 gust alone exceeds the peak righting moment.** The crew's own
weight on one rail is most of it. This is a **sheltered-water boat** as
drawn - canals, harbours, rivers - not ISO category C, and not the
coastal boat the floats were sized for. `checks()` reports it as the
first open item, every run.

### And it cannot be docked afloat any more

A fixed float cannot move out of the hull's way, so the frame cannot be
slid under a floating boat: the solid check reads **105 litres** of
float driven into the wing. Splaying the arms was the only thing that
made the afloat slide-in possible, and the screw jacks went with them.

So the boat is picked up **off a slipway**, the way every trailered boat
is: back the rig down until it floats over, then pull out. That is a
deliberate reversal of the earlier decision to dock afloat, and it is
the price of having nothing that moves.

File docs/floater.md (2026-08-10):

# The Floater — Specification and Placement

Status: **the contract for the float**. Every feature the float must
contain, what it must do, and where it lives. Geometry in
`build_float()` (`freecad/build_boat.py`), parameters in
`freecad/params.py`. When the float changes, this list is what the
change is checked against — nothing on it may be silently dropped.

## 1. What the floater is

A slim outrigger hull, **5 400 × 460 × 700 mm**, one per side, that
does four jobs:

1. **Stabiliser** — extended 0.7 m out on the sliders, it
   is the boat's righting moment in waves.
2. **Trailer** — docked in the hull's T-notch, its three wheels carry
   the boat on the road.
3. **Dinghy** — undocked as a pair joined by the bight, it is a powered
   catamaran tender.
4. **Machinery pod** — it carries its own waterjet, battery and solar,
   so it works detached from the boat.

Frame convention below: **float-local**, x along the float (0 aft,
6 000 at the nose), y across (+ outboard), z up (0 at the float's mid
height; bottom −230, deck +230).

## 2. Hull

| Item | Spec | Where |
|---|---|---|
| Body | foam-core GRP sandwich, `float_shell` schedule (PET60 15 mm, 800/600) | — |
| Nose | **spoon head**: bottom curves up from x ≈ 4 500 to the tip — no slab face to the water | forward quarter |
| Tail | flat transom carrying the jet nozzle | x 0 |
| Bottom | flat, **flush with the hull keel plane** when docked | z −230 |
| Compartments | **three watertight cells**: aft (jet pump), middle (batteries, under the hatch), forward (buoyancy/stowage) | bulkheads at x ≈ 1 900 and 4 200 |
| Rub strake | half-round, full length of the outer face at the waterline | y +200, z ≈ +40 |
| Drain plugs | one per compartment, bottom aft corner | z −230 |

## 3. Propulsion — the U-intake waterjet

The pump is **enclosed**; nothing rotating ever touches open water.
Water enters through a **U of perforated plates wrapped around the
bottom of the machinery bay** — port cheek, floor, starboard cheek —
so the intake draws from all directions and keeps feeding when heeled
or in weed:

| Item | Spec | Where |
|---|---|---|
| Pump | 2 kW enclosed cartridge | machinery bay, x ≈ 2 675 (bay centre `MOTOR_BAY_DX`) |
| Intake floor plate | perforated, ≈ 560 × 290 | bottom face, directly under the pump |
| Intake cheeks | perforated, ≈ 560 × 130, port and starboard | both side faces, bottom edge, same x as the pump |
| Hole size | 14 mm — weed drifts past, fingers stay out | all three plates |
| Nozzle | cone to ⌀ jet outlet, on the transom, low | tail, z ≈ −120 |
| Steering | differential thrust between the two floats — no rudder | — |

**Rule: the intake and the pump live at the same x.** Water travels
centimetres, not a duct.

## 4. The float has no running gear

Nothing rolls, folds or drives on the float any more. **The wheels are
on the frame** and jack straight up into pockets in the hull; the float
is a closed buoyancy body whose only job is to swing out for stability.

That is worth stating because it undoes three earlier problems at once:

- **Almost no slots.** The float keeps a notch at each wheel station
  so the wheel can go DOWN past it, but nothing passes through any
  more: **564 kg** each, against 559 when the wheels lived inside it.
- **The load path is direct.** Hull → girder → leg → wheel, instead of
  hull → girder → swing arm → float → wheel. The boat's weight no
  longer passes through the part that moves.
- **Nothing that carries the boat is on a hinge.**

### The wheels, on the frame

| | |
|---|---|
| Wheel | **155/70 R12C** trailer tyre, 522 × 155, rated 900 kg against 753 carried |
| Stations | x 1 900 and 5 200 — wheelbase **3 300**, CG 3 300 inside it, 91 kg on the coupling |
| Track | **1 820 mm**: each pocket eats the float's **inner half** (y 810 → 1 010) and the wheel centres on y ±910 |
| Leg | **swing arm**: ⌀150 × 12, 445 mm, pivot at z 445 on the girder web, 180° = **890 mm of lift**, Tr45 leadscrew actuator, self-locking. Nothing stands above the girder |
| Retracted | tyre bottom at **z 629 — 310 mm above the 319 mm loaded waterline**, wholly inside a 1 000 × 200 × 580 box in the **T-wing**, which opens at z 600 into the float recess. The keel is never cut. Out of the water, out of the flow, out of sight |

**Why the pocket takes half the float.** Keeping the wheels wholly
inboard of the girders would give a 1 300 mm track — 24.9° of tip and a
**0.46 g** rollover threshold, marginal under a boat 2.8 m tall. Moving
them out to y ±910 gives:

| Wheel at | Track | Tip | Rollover |
|---|---|---|---|
| inboard of the girders | 1 300 | 27.7° | 0.52 g |
| **half into the float** | **1 820** | **36.3°** | **0.73 g** |
| full float depth | 2 280 | 42.6° | 0.92 g |

**+11.4° and +59 % of rollover margin** for half a float's width — a tall
van is ≈0.5 g and a loaded truck 0.35–0.40 g, so this sits in normal
trailer territory. The float keeps its **outboard** half solid, so the
skin that meets the water is untouched.

## 5. Extension — the V arms

**Two arms per side**, each on a vertical pin at the frame and a
vertical pin at the float, **equal length and parallel to each other**:
a parallelogram. So the float **translates** — it never yaws, it stays
parallel to the hull at every angle. That is the whole point. A float
that toes in or out fights the boat.

Seen from above, the port and starboard sets mirror and the four arms
read as a **V**. That is not decoration — the arms sweep **aft** as
they open, so the water's push on the float drives them **further
open** and holds them against the stop. A rope pulls the float forward
to shut the V, and a latch holds it under the hull for the road.

**Nothing screws, nothing jacks, nothing telescopes.**

| Item | Spec |
|---|---|
| Arms | **2 per side**, pins at x 2 700 and 4 600 |
| Length | **900 mm** pin to pin |
| Section | **160 × 220 × 5** box, 6082-T6 |
| Open | **59°** → float **771 mm out**, 436 mm aft, parallel |
| Band | z **380 … 600** — 57 mm over the loaded waterline, top flush under the wing |
| Docked | each arm lies in a **120 × 160 groove** in the float's inner face |
| Opening | the water does it |
| Closing | a rope to a block on the frame's forward tie |
| Holding | a hard stop on the girder, and a latch for the road |
| Load | 70 % of the float's 893 kg displacement × 3.0 slam on the arm's own length → 16.6 kNm, 70 MPa, **SF 1.50** |
| Mass | **10.3 kg the arm, 55 kg the whole system** both sides |

### Why the arm is short

The arm's own length is the lever, so mass climbs with length twice
over — once in the section it needs, once in the span it spans. 900 mm
is what a 10 kg arm buys; the open angle then does the rest of the
work, because 900 × sin 59° = 771 mm of stance out of a 900 mm part.

Righting **SF 2.2** against the 1.9 required.

## 6. Energy and deck

| Item | Spec | Where |
|---|---|---|
| Battery | 2 × 12 V 100 Ah (motorcycle class), **forward compartment** — trims the dinghy against crew aft | x ≈ 4 400, under deck |
| Solar | 2 × 100 W flexible strips, flush | deck, either side of the hatch |
| Charging | from its own panels detached; from the ship's 48 V bus through the dock connector when coupled | — |
| Hatch | gasketed, over the battery/machinery access | deck, x ≈ 2 675 |
| Cleats | pop-up, one forward one aft — dinghy lines, flush when unused | deck ends |
| Nav light socket | plug-in pole for the dinghy role | nose deck |

## 7. What the floater must PERFORM

- **Buoyancy**: ≥ 500 kg of float displacement per side after the wheel
  notches (asserted in `checks()`); the pair plus bight floats the
  dinghy with two crew and ≥ 200 mm freeboard.
- **Righting**: the float pair *is* the boat's stability — the stem
  alone has GM −0.42 m. Extended, peak righting is **14.5 kNm at 13°**
  against a Beaufort 6 gust of 4.0, SF 3.6 asserted ≥ 1.9. The curve
  saturates at 13° because the float has 155 mm of freeboard.
  See [stability.md](stability.md).
- **Road**: carries the loaded boat on six wheels; bays put the axle
  inside the envelope so the rig rides low.
- **Watertight**: any one compartment flooded, the float still floats
  level enough to limp home.
- **Detachable**: docks and undocks on the water, fork-and-lock, with
  the crew in the cockpit.

## 7b. Mass — the 300 kg target, and where the 589 actually goes

Asked for a hangar under 300 kg. Every line below is **computed** —
from measured areas times a laminate schedule, or from a section times
a length — not estimated:

| Item | kg | Note |
|---|---|---|
| Float shells (GRP) | 121 | 5 400 × 460 × 700 each, PET60 15 mm core, 800/600 skins |
| U-girders | 93 | 110 × 200 × 5 alu, 5 740 long — they have to reach both wheel stations |
| Wheel swing arms | 88 | four ⌀150 × 12 arms, pivots, actuators |
| Drive + seals | 80 | 2 × 3 kW, 100:1, one face seal a side |
| Wheels + hubs | 60 | 4 × 155/70 R12C on steel |
| **V arms + ropes** | **55** | **was 209 as a telescope** |
| Bight, forward tie, drawbar | 63 | two transverse ties + the demountable A-frame |
| Locks and sundry | 30 | |
| **Total** | **589** | was 1 003 |

**300 kg is below the floor, and it is worth being precise about why.**
A braked commercial boat trailer for 3 t weighs 400–600 kg empty, and
it has no floats, no extenders, no retracting wheels and no dinghy
duty. Of the 589 here, **129 kg is the two float hulls** — those are
boat, not trailer. The metalwork is 281 kg and the drive 80.

The remaining levers, in order of size: the girders (93 kg) are sized
by road deflection over a 5.7 m span and would come down if the
wheelbase shortened; the wheel swing arms (88 kg) are sized by a kerb
strike at SF 3.4 and have margin to give.

## 7c. The drive — one motor, and where it lives

**One 6 kW motor drives the whole machine**, and it never gets wet.

```
SECTION AT THE DRIVE STATION (x 2000, the pair nearest the coupling)

        motor + 100:1 reduction, DRY in the stem
                    ┌────────┐
                    │  6 kW  │
        ════════════╧═══╤════╧════════════   cross shaft, in the
    dog clutch ══╗      │      ╔══ dog clutch   keel channel
                 ║  hull stem  ║
      ┌──────────╨──┐       ┌──╨──────────┐
      │ stub shaft  │       │ stub shaft  │   one face seal each
      │   chain ↓   │       │   ↓ chain   │
      │  [ WHEEL ]  │       │  [ WHEEL ]  │
      └── float ────┘       └──── float ──┘
```

| | |
|---|---|
| Motor | **one**, 6 kW, 48 V, mounted **dry in the hull's stem** above the keel channel — the driest, most accessible place on the boat |
| Transmission | 100:1 reduction → a **transverse shaft in the keel channel** → a **dog clutch at each stem face** |
| Coupling | the clutches engage the floats' stub shafts **as the floats dock**; undocked, the floats are purely mechanical |
| In the float | a stub shaft through **one marine face seal** and a chain case up to the driven wheel. **No electrics in the float at all** |
| Driven | the pair **nearest the coupling** (x 2 000). The forward pair free-wheels |
| Output | **1 623 Nm** at the two driven wheels — a **15 %** ramp at 3 km/h |
| Mass | 86 kg: motor and reduction 38, cross shaft and clutches 18, two chain drives 18, controls 12 |

**Why the motor is not in the wheel.** IP68 is a *static* test — the unit
is dipped, not run. A rotating seal under load can fail within minutes
on an IP68-rated motor, which is the standard warning from marine motor
suppliers. Putting the motor in the hull leaves **one rotating seal per
driven wheel**, on a stub shaft, serviceable from outside without
opening anything. It is the saildrive pattern, and it is why one motor
is possible at all: a motor per wheel has to live where the wheel is.

**Why only two wheels are driven.** Traction is needed on a ramp, and on
a ramp the pull is at the coupling. The pair nearest it does the work;
the other pair rolls. That halves the transmission and costs nothing —
1 623 Nm on two wheels still climbs 15 %.

**What does not work: lifting a pair on the road.** A coupling carries
about 100 kg of nose load, so if the front pair lifted, each remaining
wheel would carry **1 596 kg** — above the heaviest 15-inch commercial
tyre (≈1 250 kg). **All four stay down on the road.** The flip arms can
still lift a pair for manoeuvring or maintenance, just not under tow.

## 8. Scantlings — calculated, not guessed

`freecad/structure_calc.py` proves the three members that carry the
boat. 6082-T6 aluminium, 260 MPa proof, **0.60 knockdown for the weld
HAZ** and 1.5 on yield → **104 MPa allowable**. Load cases: ×2.5 road
shock on a trailer axle, ×3.0 wave slam on an outrigger.

| Member | Case | Moment | Stress | SF | Section |
|---|---|---|---|---|---|
| U-girder | 3 292 kg × 2.5 over a 3.1 m simple span | 11.0 kNm | 47 MPa | **2.2** (deflection 8.1 of 12.4 mm governs) | 110 × 240 × 6 box |
| V arm | 70 % of one float's **893 kg** × 3.0, on the arm's own 900 mm | 16.6 kNm | 70 MPa | **1.5** | 160 × 220 × 5 box, two a side |
| Swing arm (gear) | kerb strike, 0.6 g at the contact patch on the 445 mm arm | 5.1 kNm | 31 MPa | **3.4** | ⌀150 × 12 arm |

Two results changed the design:

- **The ⌀70 flip tube failed at 324 MPa** — three times over. It is now
  ⌀120 × 12.
- **The U-girder was drawn at 190 × 300 × 10 and came out at SF 39** —
  294 kg of aluminium doing a 2 kNm job. Cut to 140 × 200 × 8: still
  SF 15, and 132 kg lighter.

The swing arm at SF 1.6 is the tightest member and the one to watch: it
carries a whole float's buoyancy on a single 1.9 m cantilever, which is
the honest worst case (float pitching on a crest with the other arm
unloaded).

## 9. Open engineering (not yet modelled)

- Compartment bulkheads and the flooded-cell stability case.
- The dock connector (48 V + signals) — wet-mate, location TBD at the
  forward channel end.
- Bay liners: the wheel bays are open to water; the battery and pump
  cells must be sealed boxes within the hull, not just "inside".
- Truss lug local reinforcement (doublers in the laminate).

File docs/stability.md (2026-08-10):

# Stability — what the floats are actually for

Status: computed, not asserted from memory. Everything here comes out
of `freecad/stability.py`, which runs off `params.py` and the mass
budget. Run it: `python3 freecad/stability.py`.

## 1. The finding that reframes the boat

**The stem alone has GM −0.43 m.**

The underwater body is 1 560 mm wide and carries a 2 820 mm
superstructure with a 200 mm roof sandwich on top of it. Its own
metacentric height is *negative*. Without the floats the boat does not
float upright — it lies on its side.

So the question "do the extended floats make a difference to stability"
has a sharper answer than expected: **the floats are not a stability
aid, they are the stability.** Even docked they are doing the work; the
extension is about how much margin there is on top.

## 2. What extending them buys

| | docked | **extended** | |
|---|---|---|---|
| Float centre from CL | 1 010 mm | **1 781 mm** | |
| Overall beam | 2.48 m | **4.02 m** | |
| GM | 1.20 m | **4.59 m** | 3.8 × |
| Peak righting | 3.8 kNm @ 26° | **14.8 kNm @ 16°** | **3.9 ×** |
| Peak GZ | 0.12 m | **0.47 m** | |
| Capsize energy to the deck edge | 1.6 kJ | **5.8 kJ** | **3.7 ×** |

**Yes, dramatic — and more so than a first pass suggested: 3.9 × the
peak righting moment and 3.7 × the energy needed to roll it.** The
reason the docked figure is so poor is §1: the hull is fighting the
floats, not helping them, and docked they have almost no lever to
overcome it with.

## 3. The curve saturates at 16°, and that is the real limit

The float is **71 % immersed sitting upright** — the pair already
carries 48 % of the boat. There are **205 mm of float freeboard**.

```
   7°   the lee float goes under      no more buoyancy from it, ever
  16°   the windward float comes clear  PEAK - 14.8 kNm
  32°   the hull's deck edge immerses
  49°   the windows downflood
```

Past 16° nothing more arrives. The curve does not collapse — the
submerged lee float keeps its buoyancy and the arm only loses `cos φ` —
but it never grows again either. This is a **stiff, short-range**
stability: exactly the multihull character, and the opposite of a
ballasted monohull that keeps building righting arm to 60° and beyond.

Two consequences worth being honest about:

- Most of the stability is spent in the first 16°. A knockdown that
  gets past that has nothing new to fight it.
- Like any multihull, if it goes over it will float inverted. There is
  no ballast to bring it back.

## 4. The governing risk is windage, not the floats

| Case | Heeling | vs 14.8 kNm righting | |
|---|---|---|---|
| F6 steady, rails stowed | 2.1 kNm | SF 7.2 | fine |
| F6 gust, rails stowed | 4.0 kNm | SF 3.7 | fine |
| **F6 gust, rails standing** | **13.2 kNm** | **SF 1.12** | **fails** |

The boat presents 14.4 m² to the beam with the rails down. Stand the
solar rails up and it adds 11.6 m² at 3.2 m above the water, which
almost triples the heeling moment. **`checks()` now reports this as an
open item.** The rule is: stow the rails by Beaufort 6. It is the
rails, not the floats, that set the wind limit on this boat.

The breaking-wave heuristic is kinder: a breaker taller than the beam
will roll a small craft, so the extended stance moves that threshold
from **2.5 m to 4.0 m** — against a category C significant wave height
of 2 m. That is the single most valuable thing the extension does for
coastal work.

## 5. Where the levers are

Peak righting, extended, against each variable on its own:

| Float depth | peak | Extension | peak | KG | peak |
|---|---|---|---|---|---|
| 540 mm | 12.0 kNm | 0 mm | 3.8 kNm | 900 mm | 17.7 kNm |
| 600 | 13.0 | 400 | 9.8 | 1 100 | 16.0 |
| **700 (built)** | **14.8** | **771 (built)** | **14.8** | **1 238 (built)** | **14.8** |
| 800 | 16.4 | 1 200 | 20.3 | 1 400 | 13.4 |

- **Float depth was the cheap lever, and it has been taken.** 540 → 700
  bought **+2.8 kNm of peak righting (12.0 → 14.8) and moved the peak
  from 11° to 16°**, for no extra beam. It is not quite free: the wing underside
  caps the float's top at z 590, so the extra depth went *downward* —
  the float now hangs **110 mm below the keel** and its road clearance
  is 151 mm where the keel keeps 261. It also loads the V arms harder
  (893 kg a side instead of 690), so their section went 120 → 160 wide,
  +1.1 kg an arm.
- **Extension is the strong lever** but it costs beam, arm load and
  weight; that is why the arms are 900 mm and open 59°.
- **KG is worth more than it looks** once the hull's negative GM is
  counted properly: 900 → 1 400 mm costs 4.3 kNm, a third of the peak.
  Mass aloft is expensive on this boat.

## 6. What this file replaced, and why it was wrong

The old check was three scalars at zero heel, and each had a defect:

| Was | Wrong because |
|---|---|
| stability computed at `WL_Z = 260` | the mass budget floats the boat at **385 mm**. Every hydrostatic number was taken at a waterline the boat never sits at |
| `assert 0.30 < immersion < 0.70` | `POD_WATER[1]` equals `WL_Z` by construction, so immersion was pinned at 0.50. **No weight change could trip it.** The real figure is 71 % |
| `reserve_kg` at Cb 0.80 | `float_buoyancy()` used 0.62 on the same prism, so the reserve driving the righting moment was **12 % larger than the whole float** |
| wind lever 1.5 m | the model's own `rail_heel_moment()` used the true 3.2 m on the same area. Against a correct lever the old margin was **1.06, not 2.16** |
| no KG anywhere | the "righting moment" was a buoyancy moment about the centreline, which is not a righting arm about anything. The only vertical CG in the repo was a literal `1400` in the road tip assert |

`params.vcg()` now computes KG from the mass budget and a per-item
height table, and the laminate's own contribution from the zone areas —
which put it at **1 674 mm**, because the 200 mm roof sandwich is
222 kg sitting at z 2 860. Boat KG is **1 238 mm**.

That also corrects the road figure: the tip angle was computed off the
literal 1 400 and published as 33.0° / 0.65 g. On the computed KG it is
**36.3° / 0.74 g**.

## 7. Limits of this model

- The hull term is the linear metacentric one, so the curve is only
  quoted to the deck edge (32°). Past that the cabin box starts adding
  reserve and the real curve is better than this one shows.
- No free-surface correction — the water tanks should be baffled and
  are assumed so.
- The flooded-cell case is still open (see floater.md).
- These are engineering checks in the spirit of ISO 12217 category C,
  **not a certification**. A real category assessment needs the full
  STIX apparatus and a measured boat.

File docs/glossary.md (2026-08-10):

# Glossary — Boat-Home Project

Shared language for the design. Geometry values live in
`freecad/params.py`; this file defines the *words*.

## Hull & structure

- **Hull** — the main watertight body (Dutch-barge style: bluff rounded
  bow, full midbody, near-vertical sides, flat-ish bottom). 7.20 m long,
  2.50 m wide.
- **Dutch barge** — traditional Netherlands canal workboat shape the hull
  imitates; maximizes interior volume at shallow draft.
- **Station** — a numbered cross-section of the hull at a given length
  position; the hull surface is lofted through the stations.
- **Chine** — the hard edge where the hull bottom meets the hull side.
- **Deadrise** — the slope of the hull bottom from keel to chine (~12°).
- **Keel / keel line** — the centerline bottom of the hull; z = 0 datum.
- **Sheer / gunwale** — the top edge of the hull side, where deck meets
  topsides. The arm shoulders and balcony hinges mount here.
- **Transom** — the flat aft (rear) end of the hull; x = 0 datum.
- **Waterline (WL)** — the level water reaches on the hull at rest
  (260 mm above keel at ~2.0 t displacement).
- **Displacement** — the weight of water the hull pushes aside = the
  boat's floating weight.
- **Freeboard** — hull height above the waterline.
- **Cabin** — the living superstructure on deck (5.3 × 2.28 m inside,
  1.85 m clear over the sole under a 200 mm structural roof).
- **Sole** — the interior floor inside the hull.
- **Roof terrace / sun deck** — the walkable top of the cabin roof
  (z 2 400). A sealed structural sandwich, so nothing above it can
  ever open the living quarters.
- **Walk-on glass** — laminated safety glass rated for foot traffic:
  here 6+6 mm heat-strengthened with an SGP interlayer and an
  anti-slip frit, in 8 panes of 1 200 × 1 050.
- **Air box** — the ventilated 60 mm gap between the bonded solar
  laminates and the glass over them. It keeps feet off the panels and
  keeps the cells cool; mesh slots fore and aft give the cross-flow.
- **Point load (design)** — the 2 kN on a 50 × 50 mm patch that sizes
  walk-on glass. Its stress grows with the LOG of the pane span, which
  is why smaller panes barely thin the glass.
- **Frit** — ceramic pattern fired onto the glass; here the anti-slip
  (R11) surface of the deck.
- **Standard framed module** — an ordinary aluminium-framed PV panel
  (here 1 934 × 1 134, 500 W). Chosen for the balconies because they are
  standardised, cheap and replaceable anywhere, unlike bonded
  laminates.
- **Recessed module** — a framed panel dropped INTO the depth of the
  ladder frame rather than onto it, so the folded balcony stays inside
  the 75 mm the road-width limit allows.
- **Air draft** — height from the waterline to the highest point:
  **2.27 m**.
- **Sky dome** — the glazed conservatory over the foredeck: half a
  dome cut flat by the deck, springing from the sheer and closing onto
  the bow. Replaced the old wrap-around winter garden.

## Interior (details in [interior.md](interior.md))

- **Sole** — the cabin floor (z 350). Everything heavy sits on it, not
  above it.
- **Settee berth** — a seat that is also a single bed: 1 900 × 620 each
  side of the dinette.
- **Dinette** — the saloon: two settee berths facing each other with a
  removable table between them; drop the table onto its bearers and the
  filler cushions make a second double.
- **Athwartships bed** — a bed set ACROSS the boat. A 2 000 mm body
  fits the 2 280 mm beam, so the double eats only 1 400 mm of length.
- **Wetroom** — a heads compartment with no separate shower cubicle:
  the whole floor is the shower tray and drains to a sump.
- **Worktop / locker band** — galley counter at 900 and the run of
  lockers above it (1 450–2 200), only possible where there is no
  picture window.
- **Shelf band** — the 1 150–1 480 storage strip UNDER the window band
  in the living zones, where a locker would blind the saloon.
- **Air handler** — the indoor half of the AC heat pump, in the
  aft-starboard column beside the door, opposite its outside vent box.

## Stabilizer / hangar system

- **Float (floater, ama)** — one of the two 6.2 m outboard buoyancy
  bodies. Doubles as the road bogie: it carries the wheels ("the boat IS
  its own trailer" = the **hangar** concept).
- **Hangar** — the project's term for the integrated road-carriage function:
  floats + arms + wheels acting as the trailer and slipway carriage.
- **Arm** — rigid welded steel member connecting the hull to a float.
  Made of straight segments cut and welded at angles that follow the
  hull cross-section, so it nests against the hull in road pose.
- **Shoulder** — the arm's single pivot on the upper hull side
  (longitudinal axis) — the ONLY moving joint in the whole hangar arm.
  The rigid arm swings exactly 90° outboard from road to water pose.
- **Wrist (static)** — the welded arm-to-float connection at the arm
  tip. NOT a joint: the float is rigid on the arm; its roll follows
  the shoulder swing 1:1 (90° swing = side-to-flat).
- **Roll (float roll)** — the float's rotation about its own long axis:
  90° = on its side (road), 0° = flat on the water.
- **Jack-up stance** — *removed*. The floats nest under the hull; they
  never lift the ship. The term survives only in old commit messages.
- **Pose / mode** — a named configuration of all movable parts:
  `road`, `launch`, `harbor`, `cruise`, `anchor`, `deck`, `detached`.
- **Reserve buoyancy** — the float volume above water available to
  resist heeling. The float sits **71 % immersed** upright, so the
  reserve is the remaining 155 mm of freeboard, and it is what ends the
  righting curve at 13°. See [stability.md](stability.md).
- **GZ curve** — righting arm against heel angle, computed in
  `freecad/stability.py` for both stances. The only honest way to
  compare docked with extended.
- **Bevel (mating face)** — the 12° flat machined/molded on each float
  so it sits flush on the hull bottom in road pose (zero dead space).

## Aft entry (details in [aft_entry.md](aft_entry.md))

- **Companionway** — the boat-style entrance: sunken footwell, storm
  sill, a header you duck under, then full standing height inside.
- **Footwell / cockpit** — the sunken self-draining deck aft of the
  cabin; floor 360 mm above the waterline, scuppers through the
  transom. The hub for entering the boat and the balconies.
- **Storm sill (coaming)** — the 180 mm raised threshold under the
  door; water must rise over it to reach the living quarters.
- **Dogs** — the clamping latches that squeeze a gasketed door onto
  its frame.
- **Porch** — the fixed roof over the cockpit; its top is flush with
  the roof terrace, so it doubles as terrace floor.
- **Ship's ladder** — a stair steeper than ~45°, with stringers and
  nosed treads; the only thing that fits the aft deck's 720 mm run.
- **Boarding gate** — the gap left in the sheer rail (x 950–1450) with
  a threshold step, where you cross from the cockpit onto a balcony.
- **Folding handrail** — the ladder's single outboard rail; raised only
  when the roof terrace is in use, folded flat onto the stringer
  otherwise.

## Structure (details in [structure.md](structure.md))

- **Exoskeleton (space frame)** — external welded steel frame carrying
  every concentrated load (float arms, balconies, tow, fenders) so the
  hull skin only sees distributed water pressure.
- **Chassis rail** — the frame's main longitudinal tube at shoulder
  height, half-buried in the topsides (reads as a rubbing wale);
  carries the float-arm pins.
- **Sheer rail** — the frame's second longitudinal tube on the side-deck
  strip outside the cabin wall; carries the balcony hinges.
- **Ladder loop** — the frame's plan-view shape: two side rails closed
  by ties at bow and stern only. Transverse members amidships are
  impossible (no width outboard, floats underneath, cabin inside), so
  the loop plus the hull shell carries torsion.
- **Bow ring / stern ring** — the frame's end frames; the bow ring
  carries the tow-arch pivots, the stern ring the main waterjet.
- **Stern arch** — one wide A-arch on the transom, pin-locked in two
  poses: raised as a **gantry** (anchor sheave, winch fairlead, lights)
  at sea, or swung down-aft with a telescoping tongue as the
  **drawbar** on land. The boat tows stern-first.
- **Stem band** — the fixed external frame loop around the bow; the
  collision protection now that the arch lives aft.
- **Self-recovery winch** — 2 t electric winch on the stern tie; hauls
  the boat up a slipway when tyre grip alone is not enough.
- **Bulwark** — the raised sheer forward of the cabin standing above
  the closed foredeck plate.

## Wheels & drive (details in [wheels.md](wheels.md))

- **Caster mounting** — wheels on stub axles perpendicular to the float
  deck; this makes wheels vertical when the float is on its side (road)
  and flat on the deck when the float is level (water).
- **Stub axle** — short fixed shaft carrying one wheel; no through-axle.
- **Wheel well** — recess in the float deck the wheel disc half-sinks
  into.
- **Wheel cover / fender cover** — low lid over each flat wheel in
  water pose, open on the outboard side so the tire edge stays exposed.
- **Rolling fender** — the exposed tire edge standing proud of the hull
  in harbor pose; touches the quay wall first and rolls as the boat
  surges, protecting the hull.
- **Machinery bay** — watertight compartment inside each float housing
  the electric motor + hydraulic pump + valve manifold; gasketed deck
  hatch above it.
- **Orbital motor (gerotor)** — the hydraulic wheel-hub motor type:
  oil-filled, natively submersible, high torque at low rpm.
- **Electric-over-hydraulic** — the drive architecture: electricity
  crosses the joints (one 48 V cable), hydraulics stay entirely inside
  the float.
- **Wet-mate connector** — an electrical connector rated to be plugged/
  unplugged and operated underwater.
- **Skid steering** — steering by running the left and right driven
  wheels at different speeds; no steered axle.
- **Tongue load** — the downward weight on the car's tow hitch
  (**128 kg**, or 118 with the battery pack in the car).
- **Track** — distance between left and right wheel contact patches
  (**1 820 mm**).
- **Wheelbase** — distance from front to rear axle (**3 300 mm**).

## Solar & energy

- **Panel (module)** — one flexible solar laminate, 1700 × 1130 × 4 mm,
  ~430 W, ~6 kg. Same footprint everywhere on the boat (12 total).
- **Bifacial** — a panel producing power from both faces; used on the
  balconies (rear face harvests light reflected off the water).
- **Solar balcony** — fold-down panel deck hinged at the gunwale:
  horizontal walkway over the floats in water pose (resting on legs on
  the wheel covers), folded up over the windows on road.
- **Shutter (storm shutter)** — the balcony in its folded-up road/harbor
  position, covering the window band while still charging.
- **House bank** — the 48 V LiFePO₄ battery bank feeding drive, canopy
  actuators, and domestic loads.

## Propulsion (details in [propulsion.md](propulsion.md))

- **Rim drive (rim-driven thruster)** — propulsor whose blades are
  carried by a motor ring at their tips: no shaft, no hub, open center;
  flooded sealed stator, natively submersible.
- **Tunnel** — the bore through the float tail (or nacelle) the thruster
  sits in; protects the rotor and carries the intake grilles.
- **Weed rake / trash rack** — intake bars raked 45° aft so flow pushes
  debris along and off them instead of pinning it (hydro-plant term).
- **Reverse flush** — brief full-reverse burst that ejects debris from
  the tunnel and grille ("weed button").
- **Differential thrust** — steering by running the two float thrusters
  at different speeds/directions; replaces a rudder at low speed.
- **Nacelle** — the streamlined housing of the main thruster behind the
  transom.

## Road & regulation

- **StVZO envelope** — German road limits without special permit:
  width ≤ 2.55 m, height ≤ 4.0 m; the design's hard constraints.
- **Drawbar** — the fold-up A-frame at the bow with the ball coupling
  for the towing car.
- **Tempo-100** — German certification allowing 100 km/h trailer towing.
- **Slipway** — the concrete ramp used to drive the boat in/out of the
  water under its own wheel power (launch mode).

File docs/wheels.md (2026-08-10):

# The Wheels — Mechanism and Drive

Status: design study. Geometry lives in `freecad/params.py` (single
source of truth, asserted by `checks()`); shapes in
`freecad/build_boat.py`; scantlings in `freecad/structure_calc.py`.

## 1. Concept

**Four wheels, on the frame, on swing arms.** Each one hangs straight
down for the road and swings 180° up into a box in the **T-wing** for
the water — high enough that the retracted tyre sits **310 mm above the
waterline**, dry, out of the flow. Nothing folds, nothing swings, and
nothing that carries the boat is on a hinge.

The wheels belong to the **hangar** — the frame, the two floats, the
drawbar and the running gear, which unbolt from the boat as one unit.
That is what makes the paperwork work: the hangar is the trailer, the
boat is cargo on it. It is also why the drive has to live on the
hangar and not in the boat — detached, the hangar has to run as a
catamaran dinghy under its own power.

```
SECTION AT AN AXLE                      PLAN

  +---------------------------+          stern           bow
  |          cabin            |            |  o        o  |   x 1900
  |    ,---.         ,---.    |  pockets   |              |   x 5200
  |====| o |=========| o |====|            |  o        o  |
  |  girder         girder    |            +--------------+
  +--[FLOAT]---------[FLOAT]--+             track 1820
```

## 2. The wheel

| Item | Value | Why |
|---|---|---|
| Tyre | **155/70 R12C** (⌀522 × 155 mm) | A *trailer* tyre, not a car tyre. C-type casing, built for a load that never comes off it. LI 104 = **900 kg** against the **753 kg** each one carries. Speed rating N = 140 km/h |
| Rim | 12 × 4J, 4 × 100 or 5 × 112 | The commonest braked-trailer fitment in Europe; every trailer dealer stocks it |
| Count | **4**, at x 1 900 and 5 200 | Wheelbase **3 300**, the CG at 3 300 inside it, **91 kg** on the coupling |
| Track | **1 820 mm** | Each box eats the float's inner half; see §4 |
| Mass | 15 kg a wheel, 60 kg the set | Against 88 kg for four 15" car wheels |

### Why it shrank from a 205/70 R15

The car tyre worked, but the **hole** it needed did not. Every
millimetre of tyre diameter is a millimetre of hull cut away twice
over — once to swallow the tyre, once again in lift, because the
retracted wheel has to clear the waterline by its own radius.

| | 205/70 R15 | **155/70 R12C** | |
|---|---|---|---|
| Tyre | 668 × 205 | **522 × 155** | |
| Box, at equal duty | 1 180 × 250 × 700 | **1 000 × 200 × 580** | **−44 % of volume** |
| Four boxes | 826 L | **464 L** | out of the interior |
| Proud of the sole | 707 mm | **560 mm** | −147 mm of furniture |
| Lift needed | 954 mm | **890 mm** | 600 wing + 20 + radius |
| Arm | 477 mm | **445 mm** | half the lift |
| Wheel set | 88 kg | **60 kg** | −28 kg |
| Rated | 950 kg | 900 kg | vs 753 carried |
| Drive torque | 812 Nm | **635 Nm** | −22 %, torque = force × radius |

Less hole, less lining, less structure to work round, less lift, less
weight, and a smaller motor for the same pull. The one thing given up
is load margin — 1.20 against 1.26 — still comfortable, and a C-casing
is designed for exactly this duty where a passenger casing is not.

**It costs ground clearance unless you pay for it, and the design
pays.** The axle winds 74 mm further down than the 15" wheel needed
(`AXLE_DOWN_Z` 74 → 0), which keeps the keel **261 mm** off the road,
as before.

## 3. The swing arm

The wheel is on the **end of a 445 mm arm**, pivoted at z 445 off the
girder web. Hanging straight down the axle is at z 0 and the tyre is on
the road; swung 180° it is at z 890 with the tyre stowed in the wing.

**890 mm of travel out of a mechanism 445 mm long, and nothing stands
above the girder.**

| | |
|---|---|
| Arm | ⌀150 × 12, 6082-T6, 445 mm pivot to axle |
| Pivot | z 445, on a bracket off the girder web, ⌀190 boss |
| Sweep | 180° |
| Down | axle z 0, ground at **−261**, keel 261 mm clear |
| Up | axle z 890 — tyre bottom at **z 629**, in the wing, 310 mm above the loaded waterline |
| Actuator | Tr45 leadscrew, frame lug to a lug at 0.6 R along the arm, self-locking |
| Stress | 30.6 MPa against a 104 MPa allowable, **SF 3.4** |
| Mass | 22 kg a station — arm, pivot, bearings, actuator |

### Why not a straight jack

A straight jack needs a **column at least as long as its stroke**.
890 mm of lift therefore means a 1 140 mm tube standing off each
girder — four of them, ~960 mm proud, with the wheel dangling off a
380 mm bracket beside the tube because a coaxial telescope of that
stroke would reach z 1 800. That was drawn, rendered, and it looked
like what it was: a forest of poles with the wheels not even on them.

The arm has none of that. It is shorter than its own travel, the
wheel is *on* it, and it disappears into the wing with the tyre.

```
   ROAD                        WATER

  ──┐ pivot z 445             ──┐ pivot z 445
    │                            └───● axle z 890
    │ 445 arm                    ( o ) tyre 629..1151, in the WING
    ● axle z 0             ═══════════ wing underside z 600
  ( o )                    ~~~~~~~~~~~ WL 319
 ══════════ road z −261     nothing above the girder
```

### Over-centre — the screw does not hold the boat up

Hanging straight down, the wheel's load line runs **through the
pivot** into a hard stop. The road load goes tyre → arm → pivot →
girder as pure compression; the actuator carries almost none of it and
only has to swing the arm. That is why the arm is a strut in the
scantlings and not a cantilever: what sizes it is a **kerb strike** —
0.6 g sideways at the contact patch on the full 445 mm — not the
boat's weight.

Self-locking still matters for the stowed position, and the leadscrew
gives it: the arm parks anywhere with no power and no pin. The whole
mechanism is happy submerged; there is nothing electrical below the
girder.

## 4. The wheel boxes, and what the track buys

Each box is cut through the **wing underside at z 600** — not through
the keel — and **lined**, roof plate and four walls, so the shell
stays closed. The keel is left an unbroken bottom, and the opening
sits **281 mm above the waterline** inside the float recess: nothing
in the flow, nothing visible, nothing wet.

That is forced, not chosen. At y ±910 the hull below z 600 does not
exist — the T narrows to a 1 560 mm stem there and the rest is the
float's recess. An earlier cut of this was made at the keel and
produced exactly what it should have: four lining plates floating in
open air with no hull to join.

**The boxes stand 560 mm proud of the sole**, and that is the honest
cost. 1 000 long × 200 wide, from the wing underside at z 600 up
to z 1180 — long because the tyre comes in on an **arc**: crossing
z 600 the axle is 417 mm out from the pivot and the tyre reaches 678,
while stowed it sits back at ±261, against a sole at z 620. They sit at the hull sides, at seat height:
the two aft boxes carry the settee bases, the two forward ones are
steps at the dome threshold. There is no way to lift a wheel 890 mm
and leave the interior untouched — the alternative was to leave the
tyre 280 mm under water in an open well for the life of the boat.

Each box straddles the stem face and eats the float's **inner
half** (y 810 → 1 010, stopping exactly at the float's midline). That
is what puts the wheel centreline at y ±910:

| Wheel at | Track | Tip | Rollover |
|---|---|---|---|
| inboard of the girders | 1 300 | 27.7° | 0.52 g |
| **half into the float** | **1 820** | **36.3°** | **0.73 g** |
| full float depth | 2 280 | 42.6° | 0.92 g |

**+8.1° and +41 % of margin** for half a float's width. A tall van is
≈0.5 g and a loaded truck 0.35–0.40 g, so this sits in normal trailer
territory under a boat 2.8 m tall. The float keeps its **outboard**
half solid — the skin that meets the water is untouched — and the
narrow 200 mm box is what allowed the extra 25 mm a side without
crossing the midline.

## 4b. The notch in the float, and the launch sequence

Docked on the road, the float and the wheel-down tyre want the same
space: the tyre's inner flank runs through the float's inner-lower
corner. So the corner is **cut away** at each wheel station — 800 long
× 230 wide × 320 deep from the float bottom, the top 220 mm of the
inner half left solid — plus a **240 mm full-height slot** at the wheel
station itself, because the arm and its pivot live in the recess up to
z 445 and the float has to dock past them.

It only has to clear the wheel **down**, which is what keeps the cut
small. That imposes one rule on the order of operations:

| | |
|---|---|
| **Launching** | drive in on the wheels with the floats **docked** (road width), float free, **swing the floats out**, *then* wind the wheels up |
| **Recovering** | wheels down first, *then* swing the floats in, then drive out |

Get it backwards and the wheel tries to travel up through a solid
float. The interlock is trivial — the leg controller reads the swing
position and will not run up below 60° of swing.

Cost: **144 kg of buoyancy per float** — 564 kg of reserve a side
instead of 708 — against roughly double that if the notch had to clear
the whole 890 mm of travel. The lighter float also eases the swing
arm, which drops from 101 MPa to 68 (SF 1.0 → **1.5**).

## 4c. The frame is out of the water

The girders ran at **z 140…380** with the loaded waterline at **319** —
the structure that carries the whole boat spent every floating hour
half submerged, in salt, in a weldment that cannot be slipped for
inspection. There was room above it the whole time.

| | was | **now** |
|---|---|---|
| Girders | z 140…380, hanging under the hull | **z 600…800, in a lined channel in the wing** |
| Clearance | −179 mm (submerged) | **+281 mm above the waterline** |
| Versus the docked float | overlapped it, unmodelled | **clears it** — float top is 530 |
| Extender sliders | z 90…430, centred on the waterline | **z 380…600** |
| Clearance | −229 mm (submerged) | **+57 mm** |

The girder channel is cut into the wing underside and lined, open at
the bottom and at the stern, so the hangar still slides on from
astern. Nothing about the wheels moved: the arm pivot stays at z 445
on a bracket dropping off the girder, the axle still travels 0 → 890,
and the wing box is unchanged.

**And the swing wing had to go entirely.** See
[floater.md](floater.md) §5: a horizontal swing needs a plane clear of
the float at every angle, and this boat has 70 mm of it. The float now
slides straight out on telescopic beams that live inside the stem.

## 5. Drive

Requirement: electric, ≤ 6 km/h (the German rule that keeps the rig
out of full type approval on the slipway), and it must survive being
submerged for long periods.

**One driven wheel per side — the forward one.** Traction on four
wheels is not needed at walking pace; two driven wheels with most of
the weight over them is enough to climb a 15 % slipway.

```
48 V house bank ──► dry box bolted to the girder web, forward station:
      3 kW BLDC motor ─► 100:1 planetary ─► ONE stub shaft
        ─► marine face seal ─► forward wheel        635 Nm
```

**Why not a submerged hub motor.** IP68 is a *static* test. A rotating
seal under load, in salt, with grit, is a different problem, and hub
motors fail at exactly that interface. This design has **one
serviceable face seal per side** and nothing else rotating in the
water. The seal changes from outside without opening the box.

**Why on the girder and not in the float.** The float swings. Putting
the drive there meant a shaft or a hose crossing a moving joint, and
the wheels are no longer on the float anyway. On the girder the motor
sits a few hundred millimetres from the wheel it drives, on the same
rigid weldment, and it detaches with the hangar.

- **Torque check**: 3 100 kg on a 15 % slipway with rolling resistance
  ≈ 5.5 kN of tractive force → ~1 435 Nm total, 718 Nm per driven
  wheel at the tyre. 635 Nm at 3 kW / 100:1 covers a 6 km/h climb with
  the load transfer aft on the ramp; on a 10 % ramp it is comfortable.
- **Power check**: ~1.2 kW to hold 6 km/h on the flat, ~2.6 kW peak on
  the ramp, per side.
- **Control**: one controller per side gives forward, reverse and a
  speed differential — skid steering at walking pace. No steered axle
  is needed below 6 km/h.
- **Corrosion**: zinc anode at each hub, a freshwater flush port, and
  the box drains downward.

## 6. Main pieces, 2026 cost estimate

Prices are 2026 street-price estimates (EUR, excl. VAT variation);
URLs are representative product pages to see the item class.

| # | Item | Qty | Est. € each | Est. € total | Where to see it |
|---|---|---|---|---|---|
| 1 | Tyre 155/70 R12C 104/102N (Kenda K399, Security TR603) | 4 + 1 spare | 45 | 225 | <https://www.kendatire.com> · <https://www.reifen.com> |
| 2 | Steel rim 12×4J, 4×100 | 5 | 35 | 175 | <https://www.anhaengerteile.de> |
| 3 | Braked trailer hub + stub axle, 900 kg | 4 | 90 | 360 | <https://www.knott.de> · <https://www.alko-tech.com> |
| 4 | Swing arm: ⌀150 tube, pivot boss, bearings, hard stop | 4 | 190 | 760 | local machine shop + <https://www.skf.com> |
| 5 | Tr45 leadscrew actuator, 24 V, self-locking, with limit switches | 4 | 240 | 960 | <https://www.framo-morat.com> |
| 6 | 48 V BLDC motor 3 kW + controller | 2 | 550 | 1 100 | <https://www.goldenmotor.com> · <https://www.kellycontroller.com> |
| 7 | 100:1 planetary reduction | 2 | 320 | 640 | <https://www.apex-dynamics.de> |
| 8 | Marine face seal + housing, ⌀90 shaft | 2 | 140 | 280 | <https://www.volvopenta.com> class · SKF/CR catalogue |
| 9 | Anodes, flush ports, cabling, glands | — | — | 260 | chandlery |
| | **Total wheels + legs + drive** | | | **≈ 4 400** | |

Down from ≈ €5 600 for the six-wheel hydraulic scheme, mostly because
trailer tyres are a quarter the price of AT car tyres and two orbital
hub motors dropped out.

## 7. Model objects (FreeCAD tree)

`HangarFrame` — girders, swing arms, actuators, drive boxes, drawbar. `HangarTyres` —
the four wheels, dark. `HangarLocks` — bayonet spikes, gold.
`DriveHatchStb/Port` and `HydraulicsStb/Port` — the float's own bay,
which now holds only the **waterjet** pump and motor. Hide `HullShell`
to see the wheels inside their pockets.

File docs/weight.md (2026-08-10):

# Weight — Where the Kilos Are and How to Take Them Out

Status: study, August 2026. Every figure recomputed against the model
(`freecad/laminate.py` × `freecad/areas.json`); nothing here is a guess
about what "should" be lighter.

**Update, August 2026: the biggest lever in this study has been taken.**
The walk-on glass deck is gone, replaced by solar panels that rotate up
into guardrails ([roof.md](roof.md)) — **−305 kg**, while the array grew from 2.00 to 2.30 kWp — and the dome
glass went 8 → 6 mm — **−20 kg**. The boat is now **2 957 kg empty,
3 257 kg loaded**, inside the 3 500 kg category O2 limit with 243 kg,
where it was 3 582 kg and illegal. The rest of this study is what is
left on the table.

## 1. The insight that changes the problem

**Road mass and afloat mass are two different numbers, and only one of
them is legally binding.**

Afloat, 300 extra kilos cost 30 mm of draft on a hull with 781 mm of
freeboard — nothing. On the road, the same 300 kg decide whether the
vehicle is a category O2 trailer or a different legal animal.

So the cheapest weight saving is not to delete features. It is to
**make the heaviest consumables removable**, so they are aboard when
the boat is a boat and out of it when the boat is a trailer:

| Removable | kg | Cost of removing it |
|---|---|---|
| Fresh water, 200 L | **−200** | fill at the ramp; 20 minutes |
| 20 kWh of the battery as plug-in modules | **−143** | 30 kWh still aboard for the trip; the modules live in the car |
| **Road-only total** | **−343** | **nothing permanent** |

This alone takes the road mass from 2 957 to **2 614 kg** — while the boat still floats with 50 kWh and
full tanks. The battery has to be designed for it: **five 10 kWh
modules on rails with wet-mate connectors**, not one bonded bank. That
is a decision to take now, because it is impossible to retrofit.

## 2. Structural levers — all measured, none cosmetic

Ranked by kilos per unit of regret.

| Lever | Now | After | Saved | What it costs |
|---|---|---|---|---|
| **Roof core 200 → 60 mm on two beams** | 222 | 148 | **−74** | two alu top-hat beams under the deck; span drops from 2.4 m to 0.8 m, so the core no longer has to do the work alone |
| **Joinery in foam-core GRP, not ply** | 180 | 110 | **−70** | same interior, built from the same panels as the boat; more layup hours |
| **Float shell 18 → 12 mm + local doublers** | 159 | 141 | **−18** | doublers at the six axle landings and six arm roots; needs a load case each |
| **Hull bottom outer skin 1800 → 1400 gsm** | 130 | 115 | **−15** | only after an ISO 12215 check — this is the slam zone |
| **Roof core again**, now that no glass deck sits on it | 148 | 100 | **−48** | the sandwich only has to be a floor now, not a floor carrying a glass lid |
| **Structural total still open** | | | **−225** | no feature lost |

Then one that is a real trade:

| Lever | Now | After | Saved | What it costs |
|---|---|---|---|---|
| **Exoskeleton in 6082 aluminium, not steel** | 260 | 170 | **−90** | −90 kg is the biggest single item left, but: alu fatigues where steel does not, welds lose ~40 % of parent strength, and it needs isolating from every stainless fastener. Worth pricing, not worth assuming. |

## 3. Where the package lands

| | Empty | Loaded (crew + stores) | On the road |
|---|---|---|---|
| Before the rails | 3 282 | 3 582 | 3 282 |
| **Today** (rails + 6 mm dome) | **2 957** | **3 257** | 2 957 |
| + removables (§1) | 2 957 | 3 257 | **2 614** |
| + the remaining levers | **2 685** | 2 985 | **2 342** |
| + aluminium exoskeleton | 2 595 | 2 895 | 2 252 |

Consequences as the boat stands today:

- **Road 2 957 kg**, or 2 614 with the removables: inside category O2
  either way, so the overrun brake set stays a catalogue purchase.
- **Afloat 3 257 kg**: draft 348 mm, freeboard 802 mm.
- **Jack-up 1.27 ×** — still short of the 1.40 wanted. §4.
- **Speed and range unchanged** to within the model's precision.
- **Nothing is deleted.** Same 50 kWh afloat, same sun deck, same dome,
  same interior.

## 4. The jack-up stance is a separate problem

Float buoyancy is **4 152 kg**. At 3 257 kg loaded that is 1.27 ×,
against 1.40 wanted, so the keel will not ride fully awash. Fixing it
means buoyancy, not weight:

| Option | Effect |
|---|---|
| Float depth 900 → 1 050 mm | +690 kg of buoyancy → **1.51 ×**; costs 150 mm of road height (2 977 → 3 127, limit 4 000) |
| Float length 6.2 → 6.6 m | +270 kg → 1.38 ×; the floats already run most of the hull |
| Accept partial jack-up | the keel floats ~80 mm deep instead of awash — the stance still works for boarding and quay fending |

**Deeper floats are the clean answer** and the road height has room for
it. It is a parameter change, not a redesign.

## 5. What is deliberately not on the list

- **Battery capacity.** Cutting 50 → 30 kWh saves 143 kg and costs 40 %
  of the range. The removable-module trick gets the same road benefit
  for none of that.
- **The sun deck.** Kept in full — and it now costs 155 kg instead of
  460, because the panels became the guardrail.
  → [roof.md](roof.md)
- **Wheels and running gear** (270 kg). Six 15-inch car wheels on a slipway was
  the reason the boat can launch itself; smaller wheels dig in.
- **Interior comfort.** The 70 kg in lever 2 comes from *how* the
  joinery is built, not from having less of it.
- **Carbon in the hull skins.** 5–8× the cost for stiffness the core
  already provides, and worse impact tolerance.
  → [construction.md §7](construction.md)

## 6. Taken already

| Change | Saved | Where |
|---|---|---|
| **Walk-on glass deck → rotating solar guardrails** | **−305** | [roof.md](roof.md) |
| Dome glass 8 → 6 mm | −20 | [dome.md](dome.md) |

The first one is the model for the rest of this list: it did not delete
a feature, it deleted a *part* by making another part do two jobs.

## 7. What to decide now, because it cannot be retrofitted

1. **Modular battery** — five 10 kWh modules on rails, wet-mate
   connectors, one man can lift a module. Everything else in §1 follows
   from this.
2. **Roof beams before the roof panel is laid up** — the 60 mm core
   only works if the beams exist.
3. **Foam-core joinery** — decided at panel-ordering time, not at
   fit-out time.
4. **Float depth**, if the jack-up stance is to be kept as drawn.

## The pack travels in the car

The 50 kWh bank is **357 kg** — the single heaviest item on the boat,
and by a wide margin. It lives in two settee bases that unbolt, so on
the road it can ride in the **tow car** instead of on the trailer.

| | pack aboard | **pack in the car** |
|---|---|---|
| On the road | 2 788 kg | **2 431 kg** |
| Loaded (crew + stores) | 3 088 | **2 731** |
| Margin to the 3 500 kg O2 limit | 412 | **769** |
| Per wheel | 665 kg | **579 kg** (tyre rated 900) |
| Tongue load | +126 kg | **+117 kg** |

**The balance holds either way, and that is the point.** The battery
boxes sit at x 2 450 … 4 350, centroid 3 400, against an axle centroid
of 3 550 — almost exactly over the axles. Taking 357 kg out of a place
the axles were already carrying moves the LCG **15 mm**, and the
tongue load by 9 kg. `checks()` asserts the tongue load is in the
60–130 kg band in **both** states, because a trailer that only
balances one way is not balanced.

It also puts the mass on an axle that already has brakes and a driver
over it, instead of behind the coupling.

**One thing this exposed:** the tongue load was being computed on
`BOAT_MASS`, the 2 000 kg design figure, while the boat weighs 2 788.
It read 91 kg; the truth is **126 kg** — still in spec, but near the
top of it rather than mid-band. Fixed to use the computed mass.

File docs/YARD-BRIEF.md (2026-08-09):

# For the Builder

## What this is

A **7.2 m solar-electric boat-home that is its own road trailer**. The
stabiliser floats fold under the hull and carry six wheels, so one car
tows it and it drives itself in and out of the water on a slipway.
Designed to be built, not admired: every dimension lives in a
parametric FreeCAD model where the legal, structural and hydrostatic
limits are asserted in code, so nothing drifts silently.

The design is at **detailed-concept** stage. Geometry is complete and
consistent; scantlings, brake engineering and the mass resolution are
the work still open, and they are stated plainly rather than hidden.

## What I am asking a yard for

Not a turnkey boat. A **split build**, where the yard does the part that
needs a shop, a flat table and hands that have done it before, and the
owner does the part that only needs time:

| Scope | Who | Hours |
|---|---|---|
| Flat sandwich panels, laid up, bagged, post-cured | **yard** | 250 |
| Hull and float assembly: cutting, taping, filleting | **yard** | 350 |
| Fairing and coating | **yard or owner** | 400 |
| Steel exoskeleton, tow arch, arms | **subcontract** | — |
| Running gear, hydraulics, jets | owner | 500 |
| Interior joinery and fit-out | owner | 500 |
| Electrics, plumbing, systems | owner | 250 |
| Commissioning, trials, approvals | owner + yard sign-off | 150 |

**The specific questions for the yard:**

1. Can you quote **panel layup and shell assembly** as a package —
   103 m² of foam-core panel, hull plus two floats — to the schedule in
   [Construction](#) ?
2. Would you take the boat on **your table but my labour**: I lay up
   under your supervision, you take the structural sign-off?
3. What do you think of the **flat-panel route**? The middle 3.6 m of
   the hull is exactly developable; the ends twist up to 35 mm and I
   have three options costed for them.
4. **Fairing** — 400 h is my estimate for hull plus two floats. Is that
   the number you would use?
5. The **mass package** below takes 259 kg out of the structure and
   makes another 343 kg removable for the road. Which of those six
   levers would you actually do, and what have I missed?

## Principal particulars

| | |
|---|---|
| Length over hull | 7 200 mm |
| Beam, hull | 2 500 mm |
| Beam on the road, folded | 2 535 mm (StVZO limit 2 550) |
| Beam afloat, floats out | 4 716 mm |
| Air draft afloat | 2 260 mm |
| Height on the road | 3 002 mm (limit 4 000) |
| Draft, computed | 328 mm empty, 348 mm loaded |
| Freeboard, loaded | 802 mm |
| Mass, computed | **2 948 kg empty, 3 248 kg loaded** — inside category O2 |
| Structure | foam-core GRP sandwich, 103 m² of panel, 754 kg |
| Propulsion | 3 × 2 kW flush-intake waterjets, differential thrust, no rudder |
| Power | 4.60 kWp solar (one panel type, 20 panels), 50 kWh LiFePO₄ at 48 V |
| Speed / range | 4.7 kn maximum; 233 NM at 3 kn; solar-neutral at 4.2 kn |
| Accommodation | 5 berths, 1 850 mm headroom, 12.1 m² floor, wetroom, galley |
| Running gear | 4 × 155/70 R12C on 445 mm swing arms off the frame, 180° into boxes in the T-wing, ≤ 6 km/h |
| Road status | category O2 trailer, 243 kg inside the 3 500 kg limit |

## Construction, in one page

**Foam-core GRP sandwich**: PVC and PET core, stitched biaxial E-glass
skins, epoxy, vacuum bagged, panels laid up flat and CNC-cut from the
model. Principle throughout: **panel stiffness goes as the square of
core thickness**, so the schedule is thick core and thin skins, and the
skins are set by impact and print-through rather than by bending.

| Zone | Core | mm | Outer | Inner | kg/m² | m² | kg |
|---|---|---|---|---|---|---|---|
| Hull bottom | PVC80 | 20 | 1800 | 900 | 7.60 | 15.3 | 130 |
| Hull topsides | PET60 | 20 | 900 | 600 | 4.53 | 15.9 | 81 |
| Hull deck | PET60 | 25 | 900 | 600 | 4.83 | 4.3 | 23 |
| Float shell (both) | PVC80 | 18 | 1200 | 800 | 5.88 | 24.2 | 159 |
| Float deck (both) | PET100 | 20 | 1200 | 800 | 6.44 | 2.9 | 21 |
| Cabin walls | PET60 | 20 | 600 | 600 | 3.87 | 17.9 | 78 |
| Roof sandwich | PET60 | 200 | 900 | 900 | 16.00 | 12.4 | 222 |
| Bulkheads | PET60 | 15 | 600 | 600 | 3.57 | 9.9 | 40 |
| **Total** | | | | | | **102.8** | **754** |

Areas are measured off the 3D solids, not estimated; masses include a
1.12 margin for tapes, fillets and real resin use. Shopping list that
falls out of it: **203 kg** of dry biaxial fabric, **248 kg** of mixed
epoxy, **39.5 m²** of PVC foam and **63.4 m²** of PET foam.

Two structural decisions worth flagging to a builder:

- **The steel exoskeleton stays steel.** Every point load — six arm
  shoulder pins at ~1 000 kg each, the balconies, the tow — goes into an
  external galvanised frame, so the sandwich carries only distributed
  pressure, which is what sandwich is good at. Glass barrier ply
  wherever steel meets laminate; hard inserts under every through-bolt.
- **Post-cure the roof panels flat at ≥ 55 °C.** They sit under dark
  solar laminates behind glass and will see 60–70 °C. Room-temperature
  epoxy has a Tg of 50–60 °C and will creep. It cannot be retrofitted
  after assembly.

## The mass story, and what is still open

A builder will ask what it weighs, so: **2 948 kg empty, 3 248 kg with
crew and stores**, computed from measured areas × the laminate schedule
plus every known fitting — not estimated. That is inside the 3 500 kg
category O2 trailer limit with 243 kg to spare.

It was 3 582 kg and illegal three changes ago. What fixed it:

| Change | kg |
|---|---|
| Walk-on glass deck → **solar panels that rotate up into guardrails** | **−305** |
| Dome glass 8 → 6 mm | −20 |

The first one is the pattern worth showing a builder: it did not delete
a feature, it deleted a *part* by making another part do two jobs. The
glass existed only to protect the panels underfoot; now the panels
stand up out of the way instead, the deck is bare non-slip sandwich,
the array grew from 2.00 to **2.30 kWp**, and the deck gained the
**1 234 mm guardrail** it never had.

Still open, and worth a builder's opinion:

| | |
|---|---|
| **Jack-up stance** | floats give 4 152 kg, **1.27 ×** the loaded mass where 1.40 is wanted. That wants float *depth*, not weight: 150 mm deeper gives 1.51 × inside the road-height limit |
| **Design figure** | `checks()` still fails against an inherited 2 000 kg target that predates the computed budget. It wants re-baselining |
| **Another 225 kg** | roof core on beams, foam-core joinery, lighter float shell, lighter bottom skin — all costed in [Weight](weight.md) |

## What is already settled

- Hull form, float form, arm kinematics and the 90° swing.
- Walk-on glass roof deck sized for full building-code deck loads
  (2 kN/m² plus 2 kN on a 50 × 50 patch), solar under the glass.
- Interior layout: 5 berths, wetroom, galley, elevating double,
  batteries and water low and amidships.
- Front sky dome: 51 flat panes on 8 meridians and 2 tube purlins, no
  bent glass anywhere.
- Road-approval strategy: category O2 trailer, land drive capped at
  6 km/h, catalogue overrun brake set.

## What is not

- Scantling verification against a class rule (nothing here has been
  checked against ISO 12215 — the schedule is engineering judgement plus
  measured areas).
- Brake engineering for a swinging-arm axle.
- Float compartmentation.
- CFD or tank testing of the waterjet intakes.

Every one of those is named again, with numbers, in the open-risks
section of the main document.

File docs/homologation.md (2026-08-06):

# Road Approval — Homologating the Hangar

Status: research, August 2026. Everything here is desk research from
public sources; **none of it is a binding quote**. The one number that
matters — what a technical service will actually charge to approve
*this* vehicle — can only come from a paid pre-assessment, and §9 says
how to buy one.

**This document describes the problem the design has since solved.** The
hangar is now **detachable** ([hangar.md](hangar.md)): it is a complete
trailer in its own right, and the boat is cargo on it. That removes the
amphibian question, the 6 km/h rule and the swinging-arm brake problem
in one move — a boat trailer carrying a boat is the most ordinary
vehicle in Europe. What follows is the reasoning that led there, and it
still governs the trailer itself.

---

## 1. What is actually being approved

Three separate approvals, easily confused:

| | What | Who | Status here |
|---|---|---|---|
| **A** | the **vehicle** — road-legal on German/EU roads | IMT / KBA / RDW via a technical service | **the subject of this document** |
| **B** | the **boat** — CE marking under the Recreational Craft Directive 2013/53/EU | self-certification (cat. C < 12 m or cat. D) | self-build for own use is **exempt for 5 years** (§8) |
| **C** | the **waterway registration** — boat number, licences, insurance | WSA / national authority | routine, not covered here |

Only **A** is hard.

## 2. The fork in the road: trailer or amphibian

This decides everything, and it is a **design decision, not a legal
one**.

**Category O trailer** (O2: 750–3 500 kg) is the easy branch. A trailer
has no requirements for engine, emissions, steering or driver
controls. The list is short: brakes, lights, coupling, frame, masses,
dimensions, underrun protection, mudguards.

**Motor vehicle / amphibian** is the hard branch. The moment the
vehicle propels itself on a public road at road speed, it becomes a
motor vehicle needing whole-vehicle requirements — and amphibians are
worse than that, because German practice has an unresolved conflict:
road vehicles carry a Kfz registration under StVZO, boats carry a
different marking under the waterways rules, and **dual marking is not
provided for**. Water authorities have refused boat numbers to vehicles
already marked as motor vehicles, and the water police have refused to
accept car plates as boat marking. That fight is not one to pick.

**The Sealander precedent is exactly on point.** The Sealander swimming
caravan is registered as an unbraked caravan trailer *and* as a
category D motorboat. A Swiss court held it is **not** an amphibious
vehicle — expressly because it **has no drive of its own**. Its status
comes from *not* driving itself on the road.

### The design rule that follows

> **On the road, the wheel drive must be incapable of exceeding 6 km/h.**

German vehicle registration law (FZV) applies to motor vehicles with a
design speed **over 6 km/h**. At or below 6 km/h the drive is a
manoeuvring aid — legally the same family as the caravan movers sold by
the thousand — and the vehicle stays a trailer. The current design
targets ≤ 10 km/h on land; **drop it to 6 km/h and the whole approval
problem changes category.** That is a firmware limit plus a mechanical
one the inspector can verify, and it costs nothing on a slipway, where
6 km/h is already faster than anyone should be reversing a 2.5 t boat
down a ramp.

Slipway and yard use off the public road is unaffected — that is
private ground.

## 3. What the technical service will actually look at

Not the boat. The boat is just "the body". The file is about the
running gear:

| Item | What has to be shown | Difficulty |
|---|---|---|
| **Service brake** | > 750 kg ⇒ a braking system to UN R13; in Europe that means an **overrun (inertia) brake** — coupling head, transmission, wheel brakes, with a **brake calculation** matching axle, brake and overrun device | **the hard one — §4** |
| **Breakaway cable** | standard part with the coupling | trivial |
| **Coupling / drawbar** | E-marked coupling, D-value ≥ the combination, drawbar strength | easy if bought |
| **Arms locked in road position** | a **positive mechanical lock** per arm — not hydraulic pressure — plus a strength calculation for arm, shoulder pin and lock | **the "hangar" question — §5** |
| **Axles / suspension** | load rating covering the axle load, with the manufacturer's papers | easy if bought |
| **Lighting** | E-marked lamps, rear **triangular** reflectors (trailers only), side markers, plate light | easy |
| **Rear underrun protection, mudguards, spray suppression** | standard fittings | easy |
| **Masses and dimensions** | ≤ 2 550 mm wide, ≤ 4 000 mm high; axle loads; nose weight; a weighing | already asserted in `params.py` |
| **VIN** | assigned by the approval authority for a new build | small fee |

## 4. The brake is the real obstacle, not the hangar

This is the finding that matters most, and it is an **engineering**
problem the current design does not yet solve.

An overrun brake works mechanically: the trailer runs onto the coupling
head, a linkage pulls the wheel brakes. The approval is granted to the
**combination** of overrun device + axle + brake, and the makers
(Knott, AL-KO, BPW) supply the matching brake calculation free with
their parts. Deviate from a catalogue combination and you are asking a
technical service to accept an unproven brake system on a 2 t trailer —
which is where a €500 inspection turns into a five-figure test
programme.

Our six wheels sit on **swinging arms inside the floats**, driven
hydraulically. There is no catalogue axle to buy. Options, cheapest
first:

1. **Hydraulic overrun brakes.** The overrun device drives a master
   cylinder; hydraulic lines run out to wheel cylinders on the drums.
   This is standard on boat trailers, so certified components exist,
   and hydraulic lines survive the arm's 90° swing where a mechanical
   Bowden linkage would not. **This is the route to design for.**
2. **Brake only the middle wheels** (one "axle" pair per side) and
   carry the rest as unbraked. Braking rate still has to be met, so
   this needs the calculation to close — check it early.
3. **Electric brakes** — common outside the EU, awkward inside it, and
   they need a controller in the towing car.
4. **Bespoke brake, tested.** Real UN R13 testing. Avoid.

**Action for the CAD model:** pick the overrun device, drum brakes and
wheel cylinders from one manufacturer's boat-trailer catalogue, size
the arms around them, and keep the papers. The brake decides the
running-gear geometry, not the other way round.

## 5. The hangar itself — less scary than it looks

A trailer whose axles fold away is unusual, not illegal. There is no
rule against a movable running gear; the requirement is that in the
road position it is **locked positively and provably**:

- a **pin or over-centre lock** per arm, engaging mechanically, so loss
  of hydraulic pressure cannot fold the gear;
- a strength calculation for the arm, the shoulder pin and the lock at
  the design axle load with the usual dynamic factor;
- ideally a **road-position indicator** the driver can see.

Expect the technical service to want the calculation stamped by an
engineer. That is normal for any one-off frame — self-built trailers
are routinely asked to show material certificates and welding
provenance, which is the same conversation.

## 6. Germany — the process

**There is no EU-wide route for a trailer.** EU individual vehicle
approval under Article 44 of Regulation (EU) 2018/858 exists only for
M1 and N1 (cars and small vans). Category O gets a **national
individual approval** only, under Article 45 — in German practice a
**Vollgutachten nach § 21 StVZO** or an **Einzelgenehmigung nach § 13
EG-FGV**, drawn up by an *amtlich anerkannter Sachverständiger* at
TÜV/DEKRA/GTÜ, then registered at the Zulassungsstelle.

Steps:

1. **Pre-assessment** with a technical service. Bring drawings, masses,
   the brake concept and the 6 km/h limitation. Ask them to state in
   writing what evidence they will require.
2. **Buy the certified parts** (brakes, coupling, lamps) and keep every
   approval sheet and brake calculation.
3. **Build**, documenting welds and materials.
4. **Full assessment** — the vehicle is presented physically, weighed,
   measured, brake-tested.
5. **VIN assignment**, then **registration** (Zulassung), plates,
   insurance.
6. Optional **Tempo 100** if you want to tow at 100 km/h.

### Cost and time, Germany

Published prices are for ordinary vehicles; this one is not ordinary.
The bands below are **my estimate**, built from the published ranges
plus the extra evidence this vehicle will attract:

| | Low | High | Note |
|---|---|---|---|
| Pre-assessment / consultation | 300 | 800 | buy this first — it prices everything else |
| Engineering: arm, pin, lock, frame calculations | 1 000 | 4 000 | stamped; less if you produce the FEA yourself |
| Certified brake, coupling, lighting parts | 800 | 2 500 | hardware, would be bought anyway |
| Full assessment (§ 21 / § 13 EG-FGV) | 400 | 1 500 | published einzelabnahme range is 80–500 for normal work; this is not normal work |
| VIN assignment + registration + plates | 150 | 250 | published: ≈ €20 VIN, ≈ €123 registration |
| Contingency: re-inspection, extra evidence | 500 | 3 000 | assume at least one iteration |
| **Total** | **≈ 3 150** | **≈ 12 050** | |

**Elapsed time: 4–10 months** from first meeting to plates, most of it
waiting on your own engineering evidence, not on the authority. A
straightforward self-built trailer in Germany goes through for around
**€430 all-in** — that figure is the floor, and it is what this becomes
*if* the brake and the arm lock are bought as certified parts and the
6 km/h rule keeps it a trailer.

## 7. Portugal — cheaper, and probably faster

Portugal runs the same EU framework (Regulamento (UE) 2018/858,
Decreto-Lei 116/2014), with **IMT** as the approval authority.
Trailers, being category O, again get **national homologation** only.

Route: technical inspection at a **CITV**, laboratory tests where
required, then the **homologação individual** dossier to IMT, then
matrícula.

| | EUR | Source |
|---|---|---|
| Homologação nacional (trailer) | 160 | published |
| Matrícula with national homologation | 45 | published |
| Matrícula without prior homologation | 165 | published |
| Simple homologation application | 45 | published |
| Individual homologation, no prior certification | 165 | published |
| CITV inspection | 30–60 | typical |
| Laboratory tests, if IMT demands them | 500–3 000 | **the open variable** |
| Engineering dossier (dossiê de fabrico) | 1 000–3 000 | as in Germany |
| **Realistic total** | **≈ 1 700 – 6 500** | |

**Stated IMT timeline: 4–12 weeks**, longer where lab testing is
required. Trailers over 300 kg must be registered.

**Portugal looks materially cheaper** — the fees are an order of
magnitude below the German engineering bill, and the process is
document-led rather than inspector-led. The risk is the mirror image:
IMT may demand accredited **laboratory testing** where a German
Sachverständiger would accept a calculation, and lab testing is where
budgets die. Ask that question first.

### The catch that decides it

**You must register where you normally live.** Germany requires a
vehicle brought in by a resident to be re-registered on German plates
within **12 months** (§ 18(2) FZV), and foreign plates are only good
while the vehicle's regular base is genuinely abroad. Portuguese plates
on a boat that lives in Germany means fines and no valid insurance —
which is the part that actually hurts.

So the Portuguese route is real **if** the owner's normal residence is
(or becomes) Portugal, or the boat genuinely lives there. It is not a
shopping trip.

### And a national approval does not travel freely

Article 46 of Regulation 2018/858: *"The validity of a national
individual vehicle approval shall be restricted to the territory of the
Member State that granted it."* Another Member State **shall permit**
registration — *"unless that Member State has reasonable grounds to
believe that the relevant alternative requirements … are not equivalent
to its own"*.

In practice: a Portuguese approval is a strong argument in Germany, not
a right. German authorities can and do ask for equivalence evidence on
unusual vehicles, and this is an unusual vehicle. Budget for a partial
re-run if the boat moves country.

## 8. The boat side, in one paragraph

The Recreational Craft Directive 2013/53/EU **exempts craft built for
own use**, provided they are not placed on the EU market for **five
years** from being put into service. Sell it inside those five years
and it needs a **post-construction assessment** by a notified body
before sale — expensive and retrospective, so if there is any chance of
selling early, document the build as if it were being certified:
scantlings, stability, ISO 12217 category, CE plate data. Design
category C (coastal) or D (sheltered) allows self-certification for a
hull under 12 m, which this is.

## 9. Recommendation

1. **Cap the land drive at 6 km/h and say so on the drawings.** This is
   the single highest-value decision in the whole approval story: it
   keeps the vehicle a trailer, keeps the Sealander precedent on our
   side, and keeps us out of the amphibian dual-marking swamp.
2. **Design the running gear around a catalogue hydraulic overrun brake
   system.** The brake picks the axle geometry.
3. **Buy a pre-assessment now, before more CAD.** €300–800 at a
   technical service, in whichever country you will register. Ask for a
   written list of required evidence. Everything above is desk
   research; that letter is the real answer.
4. **Register where you live.** Portugal is cheaper on paper and worth
   pursuing *if* the boat's home is Portugal. Otherwise Germany, and
   spend the saving on engineering evidence instead.
5. **Keep a build file from the first weld** — material certificates,
   weld records, photographs, part approval sheets. It costs nothing
   during the build and is unrecoverable afterwards.

### Also worth knowing: the Netherlands

If neither country's answer is workable, the **RDW** route is the most
transparent in the EU: a self-built trailer gets an *Individueel
Goedkeuringscertificaat* at a published price list — vehicle
identification €58.50, approval assessment €72.50–110.00, IGC €72.50,
registration certificate €50.00, so **≈ €250–300 in fees** — inspected
at an RDW station, with the required certificates listed explicitly
(braking system, coupling, underrun protection). The same residency
rule applies.

## 10. Sources

- [§ 21 StVZO — Betriebserlaubnis für Einzelfahrzeuge](https://www.buzer.de/21_StVZO.htm)
- [TÜV SÜD — Vollgutachten § 21 StVZO](https://www.tuvsud.com/de-de/branchen/mobilitaet-und-automotive/import-und-zulassung/paragraph-21-gutachten)
- [Einzelabnahme 2026 — cost overview](https://www.kostenlupe.de/artikel/einzelabnahme-tuev-kosten)
- [AnhängerForum — legal requirements and real costs of a self-built trailer](https://anhaengerforum.de/forum/thread/2140-rechtliches-beim-selbstbau/)
- [§ 3 FZV — Notwendigkeit einer Zulassung (6 km/h)](https://www.gesetze-im-internet.de/fzv_2023/__3.html)
- [§ 41 StVZO — Bremsen](https://www.gesetze-im-internet.de/stvzo_2012/__41.html)
- [Regulation (EU) 2018/858 — consolidated text](https://eur-lex.europa.eu/legal-content/EN/TXT/HTML/?uri=CELEX:02018R0858-20240701)
- [Article 46 — validity of national individual approvals](https://www.legislation.gov.uk/eur/2018/858/article/46/adopted/data.htm?view=plain)
- [KBA — EU individual vehicle approvals](https://www.kba.de/EN/Themen_en/Typgenehmigung_en/Typgenehmigungserteilung_en/Spezielle_Genehmigungen_en/EU_Fz_Einzelgenehmigungen/eu_Fz_Einzelgenehmigungen_node.htm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)
- [IMT — homologação de reboques (O1–O4)](https://www.imt-ip.pt/sites/IMTT/Portugues/Veiculos/Aprovacoes/HomologacoesVeiculos/Reboques/Paginas/HomologacaoReboques.aspx)
- [Legalizar reboque caseiro — fees and documents (PT)](https://www.e-konomista.pt/legalizar-reboque-caseiro/)
- [Homologação individual no IMT — process and timeline](https://gtauto.pt/blog/homologacao-individual-imt.html)
- [RDW — self-built trailer approval and fees](https://www.rdw.nl/zakelijke-partners/fabrikant/keuren-bij-afbouw-zelfbouw-of-wijziging/aanhangwagen)
- [Sealander — caravan and category D motorboat, court ruling on amphibian status](https://www.srf.ch/news/schweiz/gerichtsurteil-zur-schifffahrt-schwimmender-wohnwagen-darf-aufs-wasser-was-das-urteil-bedeutet)
- [Recreational Craft Directive 2013/53/EU](https://eur-lex.europa.eu/legal-content/EN/TXT/?uri=CELEX:32013L0053)
- [Foreign plates in Germany — 12-month rule](https://www.anmeldefuchs.de/blog/auslandskennzeichen-in-deutschland)

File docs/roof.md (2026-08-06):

# Roof Deck — Solar Panels That Rotate Into Guardrails

Status: design study. Geometry in `freecad/params.py` (`RAIL_*`,
`rail_positions()`, `rail_footprint()`), shapes in `build_terrace()`,
limits asserted in `checks()`. Terms in [glossary.md](glossary.md).

## 1. What it is

The roof is a **12.7 m² deck you walk on directly** — the structural
sandwich with a non-slip topcoat — and **ten flexible solar panels
that rotate up into a guardrail** around it.

| Pose | What you get |
|---|---|
| **Flat** (road, passage, everyday) | 2.30 kWp harvesting, panels latched down, no deck |
| **Standing** (deck in use) | the whole 5 300 × 2 400 free to walk on, a **1 234 mm guardrail** both sides, and about a third of the output |

**Two continuous rows, five panels each, mirrored about the
centreline.** Each row is one 5 073 mm band with 12 mm shadow gaps, and
the two rows meet on the centreline with 12 mm to spare — the roof is
covered edge to edge, with no leftover strip and nothing interlaced.
Deployed, each row stands vertical on its outboard edge and latches.
One leaf hinge and one catch per panel: 12.5 kg to lift by hand,
nothing synchronised, nothing hydraulic.

## 1b. Why this replaced the walk-on glass

The glass deck existed for exactly one reason: to let people stand on
the roof without touching the panels. It did that, and it cost:

| | Walk-on glass | Rotating rails |
|---|---|---|
| Mass | 352 kg glass + 108 kg framed modules = **460 kg** | 10 × (6.5 + 6) + surface = **155 kg** |
| Cost | ≈ €5 110 | ≈ €2 900 |
| Roof array | 2.00 kWp nominal, **1.83 effective** (glass ate 9 %, the grid shaded 4.4 %) | **2.30 kWp** nominal, **2.42 effective** |
| Guardrail | **none** — an accepted fall risk, 2.4 m above the water | **1 234 mm** both sides |
| Failure mode | a cracked pane is a crane job | a damaged panel is €100 and four bolts |
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

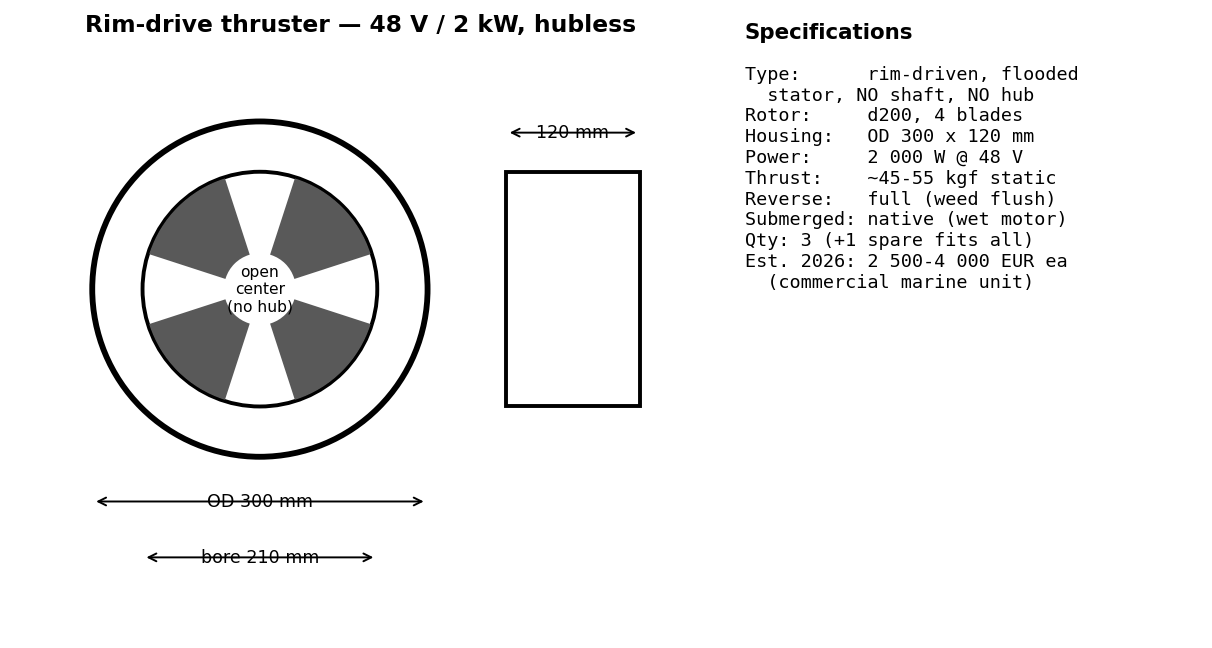
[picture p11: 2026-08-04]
docs/images/rim_thruster.png

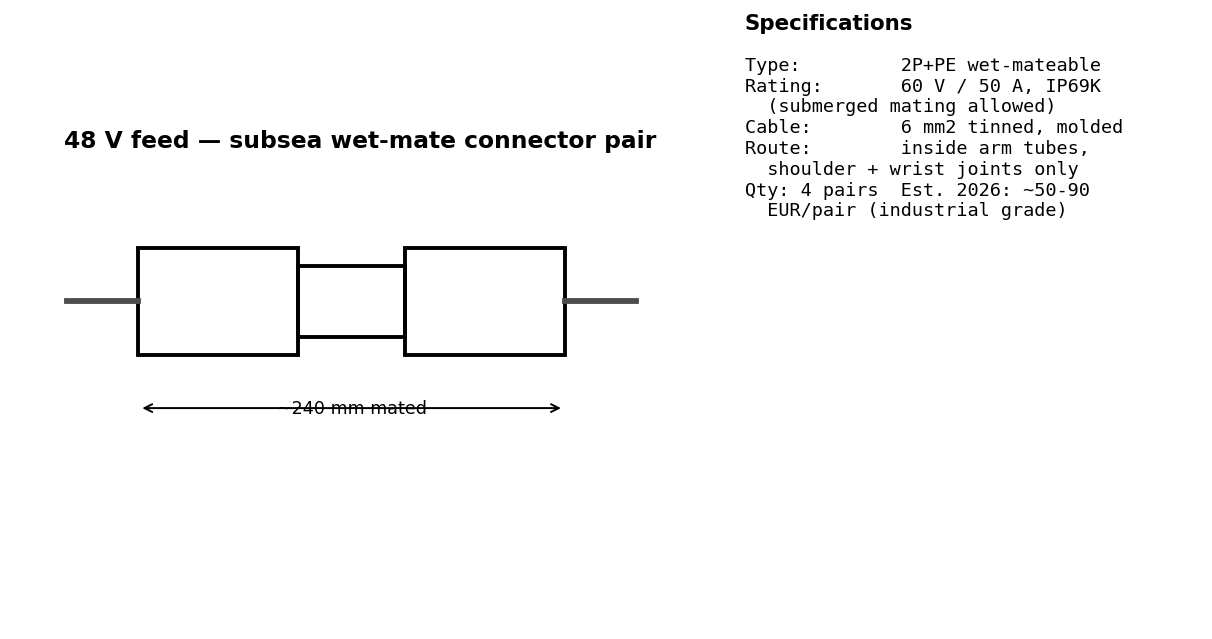
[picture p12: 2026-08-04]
docs/images/wetmate_connector.png

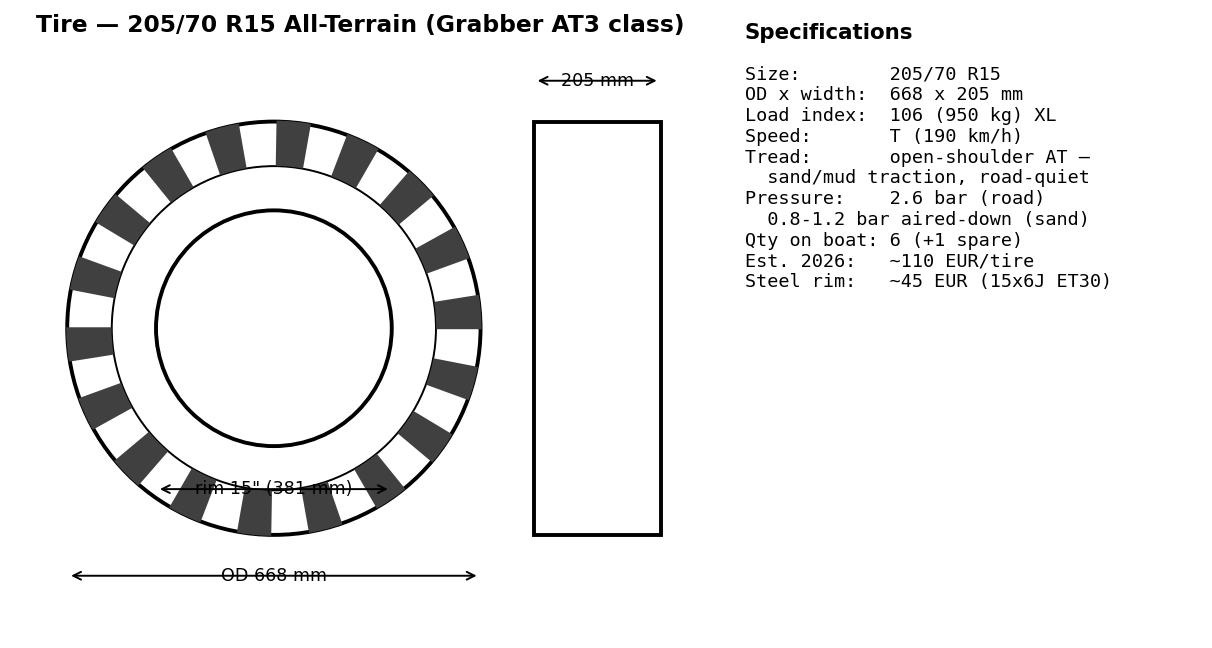
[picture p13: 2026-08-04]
docs/images/tire_205_70_r15_at.png

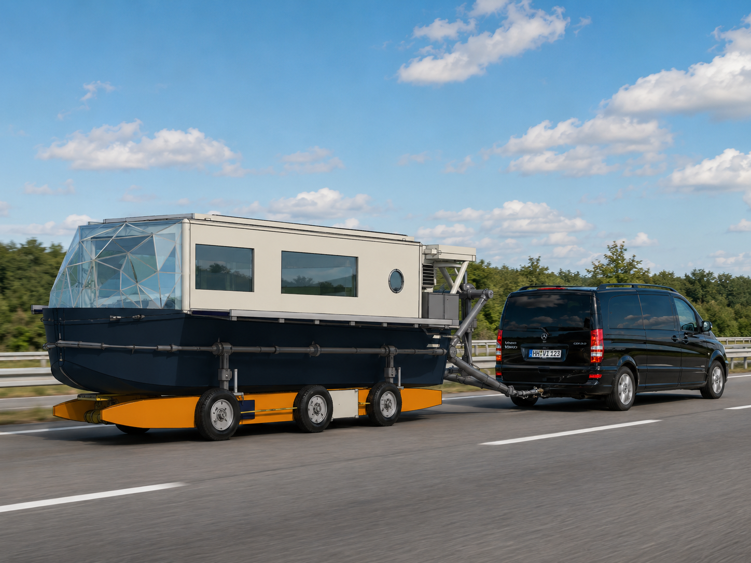
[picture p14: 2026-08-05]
docs/photo-realistic/boat-on-road.png

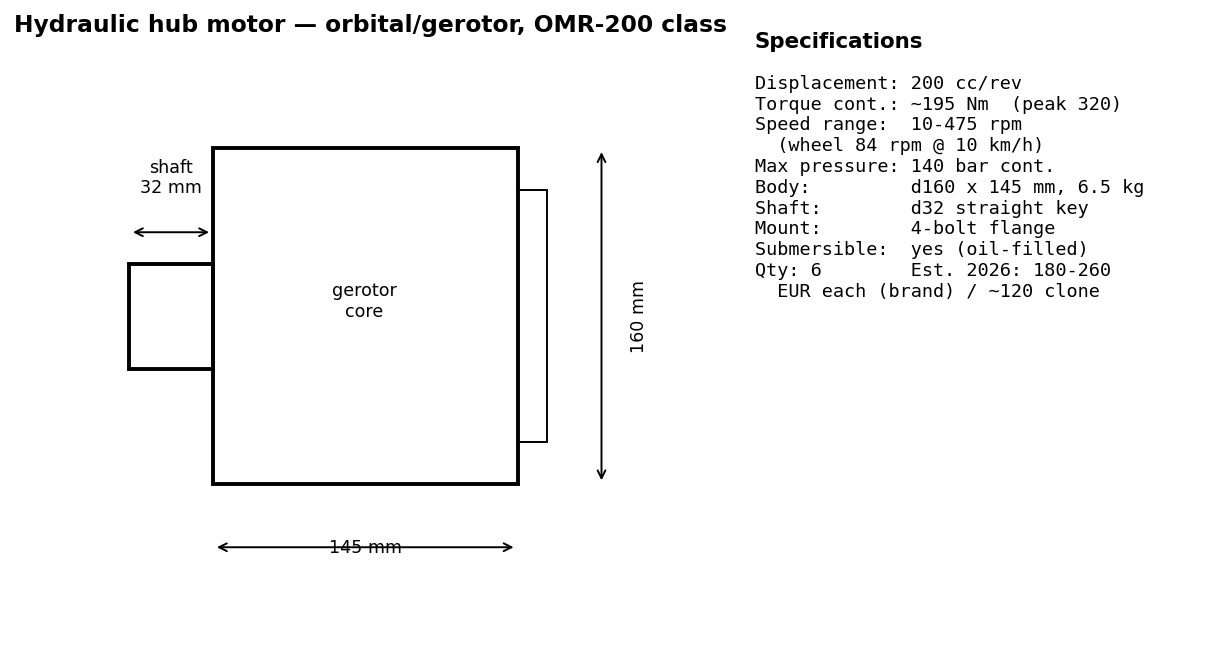
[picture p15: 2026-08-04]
docs/images/orbital_motor_omr200.png

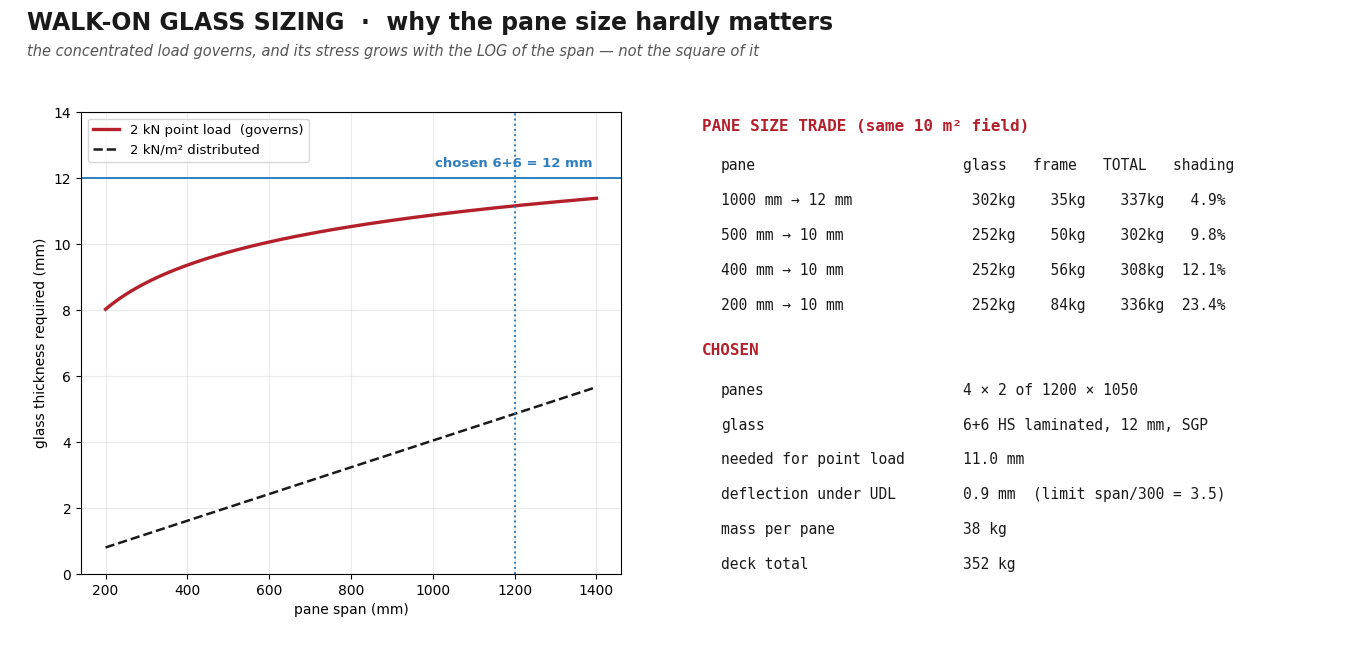
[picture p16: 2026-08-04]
docs/images/roof_glass.png

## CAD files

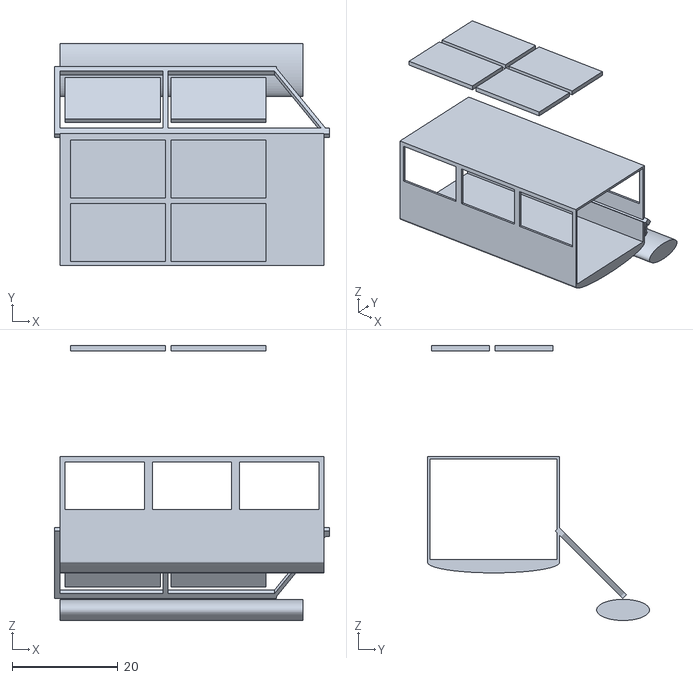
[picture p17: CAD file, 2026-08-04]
drafts/Boat_2026-08-03.stl
52.0 x 42.0 x 52.0

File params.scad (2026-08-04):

// params.scad — all master dimensions, mode tables, derived values, checks.
// Units: mm, full scale.
// Frame: x=0 at transom (+x forward), y=0 centerline, z=0 keel baseline.
// Design waterline at z = wl_z.

/* [Mode] */
mode = "cruise";     // [road, launch, harbor, cruise, foiling]
anim = false;        // true: arms/pods driven by $t (View > Animate)
target = "view";     // [view, print]  print: 1:20, no reference planes
canopy_up = false;   // pop-top raised (anchor only)

/* [Hull] */
loa = 7200;
hull_beam = 2200;    // max beam at gunwale
wl_z = 340;          // design waterline above keel (tuned for ~1900 kg)
keel_flat = 40;      // half-width of keel flat
water_rho = 1e-6;    // kg per mm^3, fresh water

// Stations: [x, y_gunwale, y_chine, z_keel, z_chine, z_sheer]
STATIONS = [
  [   0,  950, 820,  80, 260, 1150],
  [ 900, 1050, 920,  20, 250, 1150],
  [1800, 1100, 950,   0, 250, 1150],
  [2700, 1100, 950,   0, 250, 1150],
  [3600, 1100, 940,   0, 255, 1160],
  [4500, 1080, 880,  30, 280, 1190],
  [5400,  980, 720, 120, 360, 1250],
  [6300,  700, 420, 320, 560, 1330],
  [7200,   60,  30, 700, 900, 1420],
];

// Full chined section polygon in (y,z), counterclockwise
function full_section(st) =
  let (yg = st[1], yc = st[2], zk = st[3], zc = st[4], zs = st[5])
  [[keel_flat, zk], [yc, zc], [yg, zs],
   [-yg, zs], [-yc, zc], [-keel_flat, zk]];

/* [Cabin + pop-top canopy] */
cabin_x0 = 1600;
cabin_x1 = 5400;
cabin_w = 2000;
cabin_base_z = 1150;   // sits on deck at sheer
cabin_roof_z = 2150;   // roof deck = terrace floor; 1.8 m headroom inside
canopy_thick = 180;    // panel + frame + solar, stowed
canopy_lift = 1500;    // actuator stroke
canopy_overhang = 80;

/* [Hangar arms + pods] */
arm_hinge_y = 1050;    // longitudinal hinge on gunwale
arm_hinge_z = 1150;
arm_len = 1450;        // hinge to pod pivot
arm_x_front = 4700;
arm_x_rear = 1500;
arm_w = 140;           // arm box section
arm_t = 90;
arm_road_deg = -5;     // from straight down, +outboard
arm_launch_deg = 35;
arm_harbor_deg = 45;
arm_water_deg = 72;
pod_up_off = 360;      // ama center above wheel axle, pod frame (road pose)
pod_water_deg = 157;   // pod world rotation road -> water

/* [Wheels — electric hub motors] */
wheel_dia = 600;
wheel_w = 180;
hub_dia = 250;

/* [Amas] */
ama_len = 3200;
ama_w = 400;
ama_h = 440;
ama_x = (arm_x_front + arm_x_rear) / 2;   // spans both arm tips

/* [Bow hydrofoil] */
foil_x = 6500;         // forward of the V-berth, trunk clear of interior
foil_span = 1800;
foil_chord = 300;
foil_strut_chord = 220;
foil_deploy_z = -900;  // wing below keel, deployed
foil_stow_z = 420;     // wing tucked inside the keel trunk, stowed
                       // (local keel at foil_x is z~404; wing hides in hull)

/* [Drawbar + stern pod] */
drawbar_len = 1600;
coupling_h = 430;      // coupling above ground
sternpod_dia = 300;
sternpod_len = 700;

/* [Mass budget, kg — [name, mass, x_cg]] */
MASSES = [
  ["hull",          550, 3400],
  ["cabin",         330, 3500],
  ["canopy+solar",  170, 3500],
  ["arms+hinges",   160, 3100],
  ["amas",          110, 3100],
  ["wheels+motors", 150, 3100],
  ["battery",       200, 3000],
  ["hydrofoil",      60, 5900],
  ["stern pod",      40,  200],
  ["outfit/misc",   130, 3300],
];

// ---------------------------------------------------------------
// Helpers
// ---------------------------------------------------------------
function lerp(a, b, t) = a + (b - a) * t;
function sumv(v, i = 0) = i >= len(v) ? 0 : v[i] + sumv(v, i + 1);

// ---------------------------------------------------------------
// Arm / pod kinematics (same trig the modules use)
// ---------------------------------------------------------------
function arm_deg_for(m) =
  m == "road"   ? arm_road_deg :
  m == "launch" ? arm_launch_deg :
  m == "harbor" ? arm_harbor_deg :
                  arm_water_deg;          // cruise, foiling

function arm_frac(a) = (a - arm_road_deg) / (arm_water_deg - arm_road_deg);
function pod_deg_for(a) = arm_frac(a) * pod_water_deg;   // pod world roll

// arm tip (wheel axle) position in (y,z), starboard
function arm_tip(a) = [arm_hinge_y + arm_len * sin(a),
                       arm_hinge_z - arm_len * cos(a)];

// ama center offset from axle at pod world roll p
function ama_off(p) = [-pod_up_off * sin(p), pod_up_off * cos(p)];
function ama_center(a) = arm_tip(a) + ama_off(pod_deg_for(a));

// rotated ama bounding half-extents in y and z
function ama_yext(p) = ama_w / 2 * abs(cos(p)) + ama_h / 2 * abs(sin(p));
function ama_zext(p) = ama_w / 2 * abs(sin(p)) + ama_h / 2 * abs(cos(p));

// ---------------------------------------------------------------
// Derived: road mode
// ---------------------------------------------------------------
road_tip = arm_tip(arm_road_deg);
ground_z = road_tip[1] - wheel_dia / 2;      // road surface under keel datum
road_width = max(hull_beam,
                 2 * (road_tip[0] + ama_yext(pod_deg_for(arm_road_deg))),
                 2 * (road_tip[0] + wheel_w / 2));
canopy_top_z = cabin_roof_z + canopy_thick;
road_height = canopy_top_z - ground_z;
ground_clearance = -ground_z;                 // keel above road

// ---------------------------------------------------------------
// Derived: water mode
// ---------------------------------------------------------------
water_tip = arm_tip(arm_water_deg);
wheel_bottom_water = water_tip[1] - wheel_dia / 2;
ama_c_water = ama_center(arm_water_deg);
ama_zx = ama_zext(pod_water_deg);
ama_bottom_water = ama_c_water[1] - ama_zx;
ama_immersion = (wl_z - ama_bottom_water) / (2 * ama_zx);
water_beam = 2 * (ama_c_water[0] + ama_yext(pod_water_deg));

// ---------------------------------------------------------------
// Displacement at wl_z: clip each section at waterline, shoelace
// area, trapezoid integration along x
// ---------------------------------------------------------------
function clip_below(pts, zc) =
  [ for (i = [0 : len(pts) - 1])
      let (a = pts[i], b = pts[(i + 1) % len(pts)])
      each concat(
        a[1] <= zc ? [a] : [],
        ((a[1] <= zc) != (b[1] <= zc))
          ? [[a[0] + (b[0] - a[0]) * (zc - a[1]) / (b[1] - a[1]), zc]]
          : []) ];

function poly_area(pts) =
  len(pts) < 3 ? 0 :
  abs(sumv([ for (i = [0 : len(pts) - 1])
      let (a = pts[i], b = pts[(i + 1) % len(pts)])
      a[0] * b[1] - a[1] * b[0] ])) / 2;

function sub_area(st) = poly_area(clip_below(full_section(st), wl_z));

displacement_kg = sumv([ for (i = [0 : len(STATIONS) - 2])
    (sub_area(STATIONS[i]) + sub_area(STATIONS[i + 1])) / 2
    * (STATIONS[i + 1][0] - STATIONS[i][0]) ]) * water_rho;

// ---------------------------------------------------------------
// Mass / trim
// ---------------------------------------------------------------
total_mass = sumv([for (m = MASSES) m[1]]);
lcg = sumv([for (m = MASSES) m[1] * m[2]]) / total_mass;
axle_center_x = (arm_x_front + arm_x_rear) / 2;
coupling_x = loa + drawbar_len;
tongue_load = total_mass * (lcg - axle_center_x) / (coupling_x - axle_center_x);

// ---------------------------------------------------------------
// Checks — run once when params.scad is include<>d or opened
// ---------------------------------------------------------------
run_checks = true;

if (run_checks) {
  assert(road_width <= 2550,
    str("ROAD WIDTH ", road_width, " > 2550 mm (StVZO)"));
  assert(road_height <= 4000,
    str("ROAD HEIGHT ", road_height, " > 4000 mm (StVZO)"));
  assert(ground_clearance >= 250,
    str("GROUND CLEARANCE ", ground_clearance, " < 250 mm"));
  assert(wheel_bottom_water >= wl_z + 25,
    str("WHEELS WET in water mode: bottom ", wheel_bottom_water,
        " vs WL ", wl_z));
  assert(ama_immersion > 0.30 && ama_immersion < 0.70,
    str("AMA IMMERSION ", ama_immersion, " outside 30-70 %"));
  assert(water_beam >= 4500 && water_beam <= 5200,
    str("WATER BEAM ", water_beam, " outside 4500-5200 mm"));
  assert(foil_stow_z >= 0,
    str("STOWED FOIL below keel: ", foil_stow_z));
  assert(displacement_kg > 1600 && displacement_kg < 2300,
    str("DISPLACEMENT ", displacement_kg, " kg implausible at WL ", wl_z));

  echo(str("=== boat check ==="));
  echo(str("road width      ", road_width, " mm (limit 2550)"));
  echo(str("road height     ", road_height, " mm (limit 4000)"));
  echo(str("ground clear    ", ground_clearance, " mm"));
  echo(str("water beam      ", water_beam, " mm"));
  echo(str("wheel dry marg  ", wheel_bottom_water - wl_z, " mm above WL"));
  echo(str("ama immersion   ", round(ama_immersion * 100), " %"));
  echo(str("displacement    ", round(displacement_kg), " kg @ WL ", wl_z,
           "  (target ", total_mass, ")"));
  echo(str("mass total      ", total_mass, " kg, LCG x=", round(lcg)));
  echo(str("tongue load     ", round(tongue_load), " kg"));
  echo(str("air draft stowed ", canopy_top_z - wl_z, " mm above WL"));
}

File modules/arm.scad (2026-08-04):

// arm.scad — one side of the hangar: two hinged arms, wheel pods, ama.
// arm_a: main hinge angle from straight-down (+ = outboard)
// pod_p: pod world roll (road 0 -> water pod_water_deg)
// Starboard geometry; assembly mirrors for port.
include <../params.scad>
use <wheel.scad>
use <ama.scad>

module arm_beam() {
  // box arm from hinge to pod pivot, along -z in hinge frame
  color("dimgray") {
    translate([0, 0, -arm_len / 2])
      cube([arm_w, arm_t, arm_len + arm_w], center = true);
    // hinge knuckle + lock-pin boss
    rotate([0, 90, 0])
      cylinder(h = arm_w + 60, d = arm_t + 40, center = true);
  }
}

module side_assembly(arm_a, pod_p) {
  for (ax = [arm_x_rear, arm_x_front])
    translate([ax, arm_hinge_y, arm_hinge_z])
      rotate([arm_a, 0, 0]) {
        arm_beam();
        translate([0, 0, -arm_len])
          rotate([pod_p - arm_a, 0, 0]) {
            wheel();
            // ama rides on both pods; draw once, off the rear arm
            if (ax == arm_x_rear)
              translate([ama_x - arm_x_rear, 0, pod_up_off])
                ama();
          }
      }
}

side_assembly(arm_road_deg, 0);   // demo: road pose

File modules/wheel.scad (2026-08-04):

// wheel.scad — pneumatic wheel with electric hub motor, axle along y
include <../params.scad>

module wheel() {
  rotate([90, 0, 0]) {
    color([0.15, 0.15, 0.15])             // tire
      cylinder(h = wheel_w, d = wheel_dia, center = true);
    color("silver")                       // rim + hub motor cartridge
      cylinder(h = wheel_w + 50, d = hub_dia, center = true);
    color("darkorange")                   // clamshell hub cap (sealed, Solaris)
      for (s = [-1, 1])
        translate([0, 0, s * (wheel_w / 2 + 25)])
          cylinder(h = 14, d = hub_dia + 30, center = true);
  }
}

wheel();   // demo

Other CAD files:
assembly.scad
modules/ama.scad
modules/cabin.scad
modules/canopy.scad
modules/drawbar.scad
modules/hull.scad
modules/hydrofoil.scad
modules/stern_pod.scad

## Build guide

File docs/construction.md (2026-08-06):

# Construction — Foam-Core GRP Sandwich

Status: method decision, August 2026. Schedule in `freecad/laminate.py`,
areas measured off the solids by `freecad/areas.py` into
`freecad/areas.json`, mass asserted in `params.checks()`.

Primary structure is **PVC/PET foam core with biaxial E-glass skins in
epoxy, vacuum bagged**. The steel exoskeleton stays steel — see
[structure.md](structure.md).

Why, in priority order:

1. **Mass.** It is the lightest structure one person can build without a
   yard.
2. **Skills and tools.** No welding qualification, no 400 V three-phase,
   no EN 1090 conversation, no galvanic design inside the hull. Panels
   are laid up on a flat table with hand tools and a vacuum pump.
3. **Cost.** Materials cost more per kg than steel; there is no
   fabrication labour to buy and no trade to learn first.

## 1. Panel schedule

The governing principle: **panel stiffness goes as the square of core
thickness, so thicker core with thinner skins beats more glass, every
time.** Skins here are set by impact, abrasion and print-through — not
by a bending calculation.

| Zone | Core | mm | Outer | Inner | kg/m² | Panel | Purpose |
|---|---|---|---|---|---|---|---|
| Hull bottom | PVC80 | 20 | 1800 | 900 | 7.60 | 23 | slam, grounding, trailer |
| Hull topsides | PET60 | 20 | 900 | 600 | 4.53 | 22 | stiffness, not strength |
| Hull deck | PET60 | 25 | 900 | 600 | 4.83 | 27 | walked on; dome, hardware |
| Float shell | PVC80 | 18 | 1200 | 800 | 5.88 | 20 | grounding, wheel loads |
| Float deck | PET100 | 20 | 1200 | 800 | 6.44 | 22 | axle landings, denser core |
| Cabin walls | PET60 | 20 | 600 | 600 | 3.87 | 21 | distributed loads only |
| Roof sandwich | PET60 | 200 | 900 | 900 | 16.00 | 202 | carries the glass deck, 2.4 m span |
| Bulkheads | PET60 | 15 | 600 | 600 | 3.57 | 16 | shear webs, tank boundaries |

Fibre fraction **0.45** — hand layup under a bag. Only claim 0.55 if the
panels are actually infused.

**One core per panel.** No wood-and-foam sandwiches: the two move
differently with moisture and temperature and the joint between them
becomes the failure plane. Plywood appears only as **local inserts**,
routed in at every through-bolt.

**Fabric: stitched non-crimp biaxial, not woven roving.** Woven fibres
crimp over each other at every crossing and lose real stiffness for the
same weight. Skip triaxial — biax plus separate unidirectional where
axial stiffness is wanted gives better control at lower cost.

**Margin ×1.12** on every computed mass, for fillets, tapes, overlaps,
bog, and the resin you actually use rather than the resin the arithmetic
says you need. This is the single most commonly underestimated item in a
composite build.

## 2. Measured areas and structural mass

Areas are **measured off the FreeCAD solids**, not estimated:

| Zone | m² measured | kg |
|---|---|---|
| Float shell (both) | 24.18 | 159 |
| Hull topsides | 15.90 | 81 |
| Hull bottom | 15.28 | 130 |
| Cabin walls | 17.92 | 78 |
| Roof sandwich | 12.41 | 222 |
| Bulkheads | 9.94 | 40 |
| Hull deck | 4.32 | 23 |
| Float deck (both) | 2.85 | 21 |
| **Total** | **102.8 m²** | **754 kg** (margin included) |

Two things fall out of that table:

- **The floats carry more laminate area than the hull does** — 27 m²
  against 35 m² for the whole hull including deck. They are the first
  place to look when mass has to come out.
- **The roof sandwich is 222 kg for 12 m²** — 200 mm of core, because it
  spans 2.4 m carrying a walk-on glass deck. It is the heaviest square
  metre on the boat and it sits 2.4 m up, where mass hurts stability
  about three times as much as mass in the bilge.

Against the brief's hand estimates the model is lighter almost
everywhere — 103 m² measured against ~130 m² estimated, and 754 kg
against ~1 008 kg. The differences over 15 %: hull deck (4.3 vs 8 m² —
most of the deck is cabin footprint and dome opening, both cut away),
float deck (2.9 vs 8 — the float's flat top is narrow), bulkheads (9.9
vs 15) and float shell (24.2 vs 32).

## 3. Build sequence — flat panel, and the answer to "is it developable?"

**Measured, on the model:** the hull's panel strips are ruled quads
between chined stations, and their out-of-plane twist is:

| Region | Worst twist |
|---|---|
| Parallel midbody, x 1 800 – 5 400 | **0.0 mm** — exactly developable |
| Aft, x 0 – 1 800 | 21 mm |
| Bow, x 5 400 – 7 200 | **35 mm** (topsides at x 6 300) |

So: **the middle 3.6 m of the boat is flat-panel work with no jig at
all**, and the ends need either cold-forming or a light frame. 35 mm of
twist across a ~1.2 m panel is more than a 20 mm sandwich will take
cold. Options for the ends, cheapest first:

1. **Kerf the core** on the inside face and let the panel twist, then
   laminate the inner skin over the kerfs. Standard practice.
2. **A light frame-and-batten jig for the bow only** — three or four
   station moulds, not a full male plug.
3. **Re-fair the bow chine to zero twist.** The chine line is a free
   parameter; moving it can make the bow panels developable too. This is
   a hull-shape change and needs sign-off — say the word and it is an
   afternoon of numerical work in `params.py`.

Sequence:

1. **Lay up flat panels on a table**, bag them, **post-cure them flat**.
2. **CNC-cut from the FreeCAD surfaces** — the model already carries the
   geometry, so there is no lofting step.
3. **Assemble** hull and floats from cut panels: tape internal joints
   with biax, fillet with thickened epoxy, tape externally.
4. **Fair, coat, paint.**

**Post-cure is not optional.** The roof panels sit under dark solar
laminates behind glass and will see 60–70 °C. Room-temperature-cured
epoxy has a Tg of 50–60 °C: it will creep and print through. Post-cure
at ≥ 55 °C **while the panel is flat on the table** — it cannot be
retrofitted once the boat is assembled. `checks()` asserts this.

## 4. Shop requirements — this changes the workshop hunt

- **Heat.** Epoxy needs 18–25 °C and stable humidity. Below ~15 °C the
  cure stalls and you get amine blush and undercured laminate. An
  unheated tent will not do: the build needs an enclosed, heated,
  ventilated space through **two German winters**.
- **Extraction and respiratory protection.** Grinding cured glass is a
  serious exposure, not a nuisance. Extraction and P3 are equipment, not
  optional extras.
- **Vacuum consumables** run €10–20/m² per shot and are thrown away. At
  103 m² of panel that is a real line item, not a rounding error.
- **Flat table**, 6 m minimum, dead flat, plus a vacuum pump and enough
  bagging film to cover the biggest panel in one shot.

## 5. Fairing — the honest number

Full exterior fairing on the hull plus two floats is **≈ 400 hours** of
filler and longboard. It is the largest single labour item on the boat
and the one that stalls owner builds in year two. It has its own line in
the build-time table for that reason — burying it inside "hull shell"
is how a schedule stops being honest.

## 6. Materials and suppliers, German market

| Item | Quantity | Note |
|---|---|---|
| Biaxial E-glass NCF | **203 kg** dry fabric | roll quantities; 600/900/1200/1800 gsm |
| Epoxy resin + hardener | **248 kg** mixed | laminating grade, slow hardener |
| PVC foam (Divinycell H80 class) | **39.5 m²** | 18–20 mm, hull bottom and floats |
| PET foam (ArmaFORM/Airex) | **63.4 m²** | 15–200 mm, topsides, cabin, roof, bulkheads |
| Plywood inserts | as needed | 18 mm, every through-bolt |

Suppliers: **R&G Faserverbundwerkstoffe**, **HP-Textiles**,
**Lange+Ritter** (roll quantities), **Diab** or **Gurit** for PVC,
**Armacell/Airex** for PET. Buying full rolls is typically **25–40 %
cheaper** than cut lengths, and at this surface area full rolls are
consumed anyway.

## 7. Where carbon is worth it

- **Not** in the hull or float skins. You would pay 5–8× for stiffness
  the sandwich already gets from core thickness, and lose impact
  tolerance doing it.
- **Yes**, consider it for the roof and glass-deck substructure. That
  mass sits 2.4 m up and works directly against righting moment; **mass
  aloft costs roughly three times what mass in the bilge costs.**
- **Isolate carbon from aluminium** with a glass barrier ply wherever
  they meet. The galvanic couple is aggressive and it eats the
  aluminium, not the carbon. Relevant at the alu roof grid.
- Carbon fails without warning where glass cracks first. Do not use it
  anywhere a warning matters.

## 8. Open questions back to the owner

**Q3 — float schedule.** The floats are 159 kg of laminate for 24 m².
A lighter schedule (12 mm PVC80, 900/600 skins → 4.29 kg/m²) saves
**≈ 38 kg** but the floats take slipway grounding and the wheel
stub-axle reactions. Proposal: lighter base schedule with **local
doublers** at the six axle landings and the six arm roots, rather than
carrying heavy skins over the whole 24 m². Needs a load case per
landing before it is more than a proposal.

**Q4 — float compartmentation.** Not currently modelled, and it should
be. The floats hold the drive motors, pumps and hydraulics *and* they
are the reserve buoyancy in the jack-up stance. Holing one on a slipway
today loses the whole float. Recommendation: **three watertight
compartments per float** — machinery bay amidships, buoyancy cells fore
and aft — so a holed cell costs a third of one float, not half the
boat's reserve. Cheap in composite (three bulkheads per float, already
in the schedule), impossible to retrofit.

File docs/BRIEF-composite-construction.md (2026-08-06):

# BRIEF — switch primary structure to foam-core GRP, and force the mass budget to close

Hand this to Claude Code in the `boat-home` repo. It describes a construction-method
change plus the model/doc work needed to carry it through `params.py`, `checks()`,
the README and the PDF.

Read `README.md`, `docs/structure.md`, `docs/interior.md` and `freecad/params.py`
before starting. Nothing here should be applied blindly — where a number below
conflicts with something already computed in the model, the model wins and the
conflict gets reported back, not silently overwritten.

---

## 0. The two changes

**A. Construction method.** Primary structure moves to foam-core GRP sandwich:
PVC/PET foam core, biaxial E-glass skins, epoxy resin, vacuum bagged. This replaces
whatever the current hull/float construction assumption is in `structure.md`.

Rationale, in priority order:

1. **Mass.** It is the lightest structure buildable by one person without a yard.
2. **Skills and tools.** No welding qualification, no 400 V three-phase, no
   EN 1090 conversation, no galvanic-corrosion design in the hull. Panels can be
   laid up on a flat table with hand tools and a vacuum pump.
3. **Cost.** Materials are higher per kg than steel, but there is no fabrication
   labour to buy and no shop rate to pay.

**B. Mass budget.** `checks()` currently lets `DESIGN_ALL_UP = 2000 kg` coexist with
a performance model run at 2 600 kg and a §7 risk note saying the structure does not
fit in what's left. That inconsistency has to become a hard failure.

**What does not change:** the steel exoskeleton, the wheels/hangar kinematics, the
waterjets, the walk-on glass deck, the interior layout, the road-approval strategy.
See §9.

---

## 1. Laminate schedule — new module

Create `freecad/laminate.py`. It owns areal masses so that structural mass is
*computed* from geometry rather than estimated in prose.

```python
"""Laminate schedule. Areal masses include resin at the stated fibre fraction."""

FIBRE_FRACTION = 0.45          # hand layup + vacuum bag; 0.55 only if infused
RESIN_DENSITY  = 1150          # kg/m3, epoxy
GLASS_DENSITY  = 2560          # kg/m3, E-glass

CORES = {
    "PVC80":  {"rho":  80, "note": "Divinycell H80 class - bottom, slam, hardware"},
    "PET60":  {"rho":  60, "note": "ArmaFORM/Airex PET - topsides, cabin, deck"},
    "PET100": {"rho": 100, "note": "float deck under wheel stub axles"},
    "PLY18":  {"rho": 650, "note": "local inserts at every through-bolt"},
}

# zone: (core, core_mm, outer_skin_gsm, inner_skin_gsm)
ZONES = {
    "hull_bottom":   ("PVC80",  20, 1800,  900),
    "hull_topsides": ("PET60",  20,  900,  600),
    "hull_deck":     ("PET60",  25,  900,  600),
    "float_shell":   ("PVC80",  18, 1200,  800),
    "float_deck":    ("PET100", 20, 1200,  800),
    "cabin_walls":   ("PET60",  20,  600,  600),
    "roof_sandwich": ("PET60", 200,  900,  900),   # per roof.md, carries glass deck
    "bulkheads":     ("PET60",  15,  600,  600),
}

def skin_areal(gsm):
    """kg/m2 of one cured skin at FIBRE_FRACTION."""
    return (gsm / 1000.0) / FIBRE_FRACTION

def panel_areal(zone):
    core, mm, outer, inner = ZONES[zone]
    core_kg = CORES[core]["rho"] * mm / 1000.0
    return core_kg + skin_areal(outer) + skin_areal(inner)
```

Add a `LAMINATE_MARGIN = 1.12` factor applied to every computed structural mass —
covers fillets, tapes, overlaps, bog and the resin you will actually use rather
than the resin the arithmetic says you need. Do not omit this; it is the single
most commonly underestimated item in a composite build.

**Do not stack two cores.** If `structure.md` anywhere describes wood *and* foam
in the same panel, remove it — one core per panel.

---

## 2. `params.py` additions

```python
# --- construction -------------------------------------------------------
CONSTRUCTION       = "foam_core_grp"
BUILD_METHOD       = "flat_panel"      # or "male_jig"; see open question Q1
VACUUM_METHOD      = "wet_layup_bagged"  # not infusion; see docs/construction.md
POST_CURE_C        = 55                # deck panels see 60-70 C under the glass
LAMINATE_TOL_MM    = 3                 # per side, as-built thickness tolerance
```

Then **compute** these from the FreeCAD geometry rather than hard-coding them —
that is the whole point of the exercise:

- `AREA_HULL_BOTTOM`, `AREA_HULL_TOPSIDES`, `AREA_HULL_DECK`
- `AREA_FLOAT_SHELL`, `AREA_FLOAT_DECK` (both floats combined)
- `AREA_CABIN_WALLS` (net of glazing openings)
- `AREA_ROOF_SANDWICH`
- `AREA_BULKHEADS`

My rough hand estimates, **for sanity-checking the computed values only** — if the
model disagrees by more than ~15%, report it rather than adopting my numbers:

| Zone | Est. area | Est. areal | Est. mass |
|---|---|---|---|
| Hull bottom | 18 m² | 11.6 kg/m² | 209 kg |
| Hull topsides | 13 m² | 4.5 kg/m² | 59 kg |
| Hull deck | 8 m² | 4.8 kg/m² | 38 kg |
| Float shell (both) | 32 m² | 5.9 kg/m² | 189 kg |
| Float deck (both) | 8 m² | 6.4 kg/m² | 51 kg |
| Cabin walls | 22 m² | 3.9 kg/m² | 86 kg |
| Roof sandwich | 14 m² | 15.3 kg/m² | 214 kg |
| Bulkheads | 15 m² | 3.6 kg/m² | 54 kg |
| **Subtotal** | | | **~900 kg** |
| × 1.12 margin | | | **~1 008 kg** |

The float shell is the surprise: two 6.2 m floats carry more skin area than the
hull does. Flag that in `structure.md` — it is the first place to look if mass
needs to come out.

---

## 3. `checks()` — new asserts

### 3.1 Mass closure (this one is expected to FAIL on first run — that is the point)

```python
structural = sum(panel_areal(z) * AREAS[z] for z in ZONES) * LAMINATE_MARGIN
known      = (structural + MASS_EXOSKELETON + MASS_WHEELS_HUBS
              + MASS_ARMS + MASS_JETS + MASS_BATTERY + MASS_INTERIOR
              + MASS_GLASS_DECK + MASS_SOLAR + MASS_ELECTRICS)
assert known <= DESIGN_ALL_UP, (
    f"mass budget does not close: {known:.0f} kg computed "
    f"vs {DESIGN_ALL_UP} kg design figure")
```

Do **not** raise `DESIGN_ALL_UP` to make this pass. Report the computed figure and
stop. Resolving it is my decision — see Q2 in §10.

### 3.2 Single mass figure

`DESIGN_ALL_UP` (§1) and the mass used in `performance.md` must be the same
variable. Right now §1 says 2 000 kg and §2 computes at 2 600 kg. Wire the
performance model to `DESIGN_ALL_UP` and let the speed/range table move.

### 3.3 Waterline follows mass

Stop asserting `draft == 260 mm`. Compute the waterline from `DESIGN_ALL_UP` and
the hull's hydrostatics, and assert instead:

- freeboard at the computed waterline ≥ some minimum
- the jack-up stance still works: float buoyancy ≥ 1.4 × all-up mass
- ground clearance in road mode unaffected (it is set by geometry, not draft)

### 3.4 Road width tolerance — new, and tight

`BEAM_ROAD = 2535 mm` against a 2 550 mm StVZO limit is **15 mm of total margin,
7.5 mm per side.** In welded metal that is fine. In hand-laid composite it is not
automatically fine: skin thickness varies with layup technique, and a bog-and-fair
coat adds 1–3 mm per side on its own.

```python
assert BEAM_ROAD + 2 * (LAMINATE_TOL_MM + FAIR_COAT_MM) <= 2550, (
    "as-built road beam can exceed the StVZO limit")
```

If that fails, the fix is to take the nominal beam down to ~2 500 mm and spend the
margin on build tolerance. **This is the single most likely way the boat becomes
road-illegal after it is built**, and it is much cheaper to fix in `params.py` than
in a mould.

### 3.5 Post-cure vs deck temperature

The roof sandwich sits under dark solar laminates behind glass. Assert
`POST_CURE_C >= 55` and note in `roof.md` that room-temperature-cured epoxy
(Tg ≈ 50–60 °C) will creep and print through under that deck. Panels must be
post-cured while flat on the table — it is effectively impossible to retrofit
once assembled.

---

## 4. New document: `docs/construction.md`

Written to the same standard as the other `docs/*.md`. Cover:

**Panel schedule** — the `ZONES` table above, in human-readable form, with the
reasoning for each core density. Key principle to state explicitly: *panel
stiffness goes as the square of core thickness, so thicker core and thinner skins
beats more glass every time.* Skins are set by impact, abrasion and print-through,
not by bending calculation.

**Build sequence** — the flat-panel route, assuming it survives Q1:

1. Infuse or bag flat sandwich panels on a table (repeatable, near-perfect, one
   person, no jig fairing).
2. CNC-cut panels from the FreeCAD surfaces — the model already has the geometry,
   so no lofting.
3. Assemble hull and floats from cut panels; tape internal joints with biax,
   fillet with thickened epoxy, tape externally.
4. Fair, coat, paint.

**Consumables and shop requirements** — this changes the workshop hunt materially
and needs saying plainly:

- Epoxy needs 18–25 °C and stable humidity. Below ~15 °C cure stalls and you get
  amine blush and undercured laminate. An unheated tent will not do; the build
  needs an enclosed, heated, ventilated space through two German winters.
- Grinding cured glass is a serious respiratory exposure, not a nuisance. Extraction
  and P3 protection are equipment, not optional extras.
- Vacuum consumables run ~€10–20/m² per shot and are discarded.

**Fairing** — state the honest number. Full exterior fairing on hull plus two floats
is several hundred hours of filler and longboard. It is the largest single labour
item and the one that stalls owner builds in year two. It belongs in the build-time
table (§6) as its own line, not buried in "hull shell, bulkheads, fairing".

**Suppliers, German market** — R&G Faserverbundwerkstoffe, HP-Textiles,
Lange+Ritter (roll quantities), Diab or Gurit for PVC, Armacell/Airex for PET.
Note that buying full rolls is typically 25–40 % cheaper than cut lengths, and at
this surface area full rolls will be consumed anyway.

**Fabric note** — specify stitched non-crimp biaxial, not woven roving. Woven fibres
crimp over each other at every crossing and lose real stiffness for the same weight.
Skip triaxial: biax plus separate unidirectional where axial stiffness is wanted
gives better control at lower cost.

---

## 5. Where carbon is and is not worth it

Add to `structure.md`. Short version:

- **Not** in hull or float skins. Paying 5–8× for stiffness the sandwich already
  gets from core thickness, and losing impact tolerance to do it.
- **Yes**, consider it for the roof/glass-deck substructure. That mass sits 2.5 m
  up and works directly against righting moment. Mass aloft is worth roughly three
  times mass in the bilge.
- **Isolate carbon from aluminium** with a glass barrier ply wherever they meet —
  the galvanic couple is aggressive and it eats the aluminium, not the carbon.
  Relevant at the alu roof grid.
- Carbon fails without warning where glass cracks first. Do not use it anywhere a
  warning matters.

---

## 6. README edits

**§4 Key systems** — add a `Construction` bullet before `Roof deck`, one paragraph,
pointing to `docs/construction.md`.

**§5 Cost table** — replace the `Hull shell, structure, fairing` and `Floats` lines
with a computed breakdown. Drive it from areas × areal mass × unit price so it
updates with the model:

| Item | Low | High | Source |
|---|---|---|---|
| Foam core, PVC + PET, by zone | 3 800 | 5 200 | construction.md |
| Glass fabric, biax NCF, roll qty | 2 200 | 3 000 | construction.md |
| Epoxy resin + hardener + fillers | 4 500 | 6 500 | construction.md |
| Vacuum consumables | 1 200 | 2 000 | construction.md |
| Fairing compound, primer | 900 | 1 500 | construction.md |
| Tooling: pump, table, extraction, PPE | 1 500 | 2 500 | construction.md |

Materials total goes **up** slightly against the current 12 000–18 000 + 3 500–4 500
for hull and floats. The saving is not in the material line — it is that there is
no fabricator invoice and no equipment purchase for a trade you would have to learn.
Say that explicitly rather than claiming composites are cheaper, because on the
materials line they are not.

**§6 Build time** — split `Hull shell, bulkheads, fairing` into:

| Phase | Hours |
|---|---|
| Panel layup and post-cure | 250 |
| Hull and float assembly, taping, filleting | 350 |
| Fairing and coating | 400 |

That pushes the total to roughly 3 100 h, i.e. ~4 years at 15 h/week or ~2.4 years
at 25 h/week. Update the bullets under the table. This is a real increase and it
should not be smoothed over — composite is lighter and needs no trade skills, but
it is not faster than welding.

**§7 Open risks** — rewrite. Remove any risk relating to welding or metal
fabrication. Add:

1. **Mass budget — still the binding constraint.** State the computed figure from
   §3.1 and the chosen resolution.
2. **Road beam tolerance.** 15 mm of margin against StVZO on a hand-built
   laminate. See §3.4.
3. **Fairing labour.** 400 h is the estimate; it is the item most likely to
   overrun and the one that stalls projects.
4. **Workshop conditioning.** Two heated winters, not a tent.
5. Keep the existing brake/homologation, jet hydrodynamics and shoulder-pin
   fatigue risks unchanged — none are affected by this decision.

---

## 7. Things to leave alone

Explicitly do **not** touch these while implementing the above:

- **The steel exoskeleton stays steel.** An external frame taking every point load
  so nothing structural crosses the living volume is a good decision and it works
  even better with composite panels — the panels then carry only distributed loads,
  which is exactly what sandwich is good at. Isolate steel from laminate with a
  glass barrier and bed fittings in ply or high-density inserts.
- Wheels, hangar kinematics, hub stack, hydraulics.
- Waterjets, intake grilles, weed strategy.
- Walk-on glass deck sizing and the 8-pane layout.
- Interior layout and the sky dome geometry.
- The road-approval strategy: O2 trailer, ≤ 6 km/h land drive, catalogue overrun
  brake set. **Note:** if the mass resolution in Q2 lands above 3 500 kg, the O2
  category is exceeded and the whole homologation route changes. Check this and
  flag it loudly if so.

---

## 8. Deliverables

1. `freecad/laminate.py` — new
2. `freecad/params.py` — construction block, computed areas, updated `checks()`
3. `docs/construction.md` — new
4. `docs/structure.md` — revised for composite + carbon guidance
5. `README.md` — §4, §5, §6, §7 as above
6. `docs/make_pdf.py` run to regenerate `docs/boat-home.pdf`
7. A short report of what `checks()` now fails on, with the numbers

---

## 9. Questions to come back to me with — do not guess

**Q1 — Are the hull and float surfaces developable?** Check Gaussian curvature on
the hull and float surfaces in the FreeCAD model. If they are developable or near
enough, flat-panel construction works and the build gets dramatically simpler: no
jig, no batten fairing, panels cut flat and folded up. If they are not, we need a
male frame-and-batten jig and the build sequence in `construction.md` changes.
This single answer determines roughly a year of schedule. Answer it first.

**Q2 — Mass resolution.** Once §3.1 gives a real number, present the options with
consequences rather than picking one:
(a) accept ~3 000 kg, tow with a 3 500 kg-rated vehicle, resize the brake set,
    confirm still inside category O2;
(b) delete or reduce the walk-on glass deck (460 kg — the largest discretionary
    item on the boat);
(c) reduce battery to 30 kWh (−140 kg) and accept the range hit;
(d) some combination.
Include what each does to the §2 speed/range table.

**Q3 — Float shell schedule.** The floats carry more laminate area than the hull.
Is there a lighter schedule that still takes slipway grounding loads and the wheel
stub-axle reactions, with local reinforcement only where the arms and axles land?

**Q4 — Do the floats need to be watertight-compartmented?** They contain the drive
motors, pumps and hydraulics and they are the boat's reserve buoyancy in jack-up
stance. If one is holed on a slipway, what does the stability picture look like?
This is not in the current documents and it should be.

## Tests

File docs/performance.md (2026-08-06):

# Performance — Speed, Range and How They Were Estimated

Status: first-order estimate. Numbers reproduced by
`docs/perf_model.py`; the summary table lives in the
[README](../README.md) §2.

## 1. The model

No tank test exists, so this is a resistance estimate with every
assumption stated. Treat the speeds as ±10 % and the ranges as ±20 %.

| Input | Value | Why |
|---|---|---|
| Waterline length | 6.60 m | 7.20 LOA less the tapered stem |
| Beam / draft | 2.50 m / **0.37 m** | the draft now FOLLOWS the mass, `params.draft_for()` |
| Displacement | **3 582 kg** | the computed mass budget, loaded — `params.mass_budget()` |
| Wetted surface | **28.0 m²** | hull + two floats, at the computed draft |
| Installed power | **6 kW** | 3 × 2 kW waterjets |
| Propulsive efficiency | **0.45** | small waterjets are poor at low speed |
| Usable battery | 45 kWh | 50 kWh × 90 % depth of discharge |

**Friction** from the ITTC-57 line, Cf = 0.075 / (log₁₀Re − 2)².

**Residuary resistance** is where a barge hurts. A block coefficient
near 0.75 on an L/B of 2.6 makes waves early, so the friction is scaled
by (1 + f) with f rising steeply once the Froude number passes 0.20:

```
f = 0.6 + 140 · max(Fn − 0.20, 0)^1.7        Fn = V / √(g·LWL)
```

That is a shape fitted to published barge and canal-boat data rather
than a first-principles calculation — it is the weakest link here and
the reason for the ±10 %.

## 2. Results

| Speed | Fn | Resistance | Shaft power | Range (45 kWh) | Endurance |
|---|---|---|---|---|---|
| 2.0 kn | 0.13 | 81 N | 0.18 kW | 488 NM | 244 h |
| 3.0 kn | 0.19 | 169 N | 0.58 kW | 233 NM | 78 h |
| 3.5 kn | 0.22 | 258 N | 1.03 kW | 153 NM | 44 h |
| 4.0 kn | 0.26 | 470 N | 2.15 kW | 84 NM | 21 h |
| 4.5 kn | 0.29 | 849 N | 4.37 kW | 46 NM | 10 h |
| **4.7 kn** | 0.30 | — | **6.0 kW** | 32 NM | 7 h |

**Maximum ≈ 4.7 kn.** The boat is *power*-limited, not hull-speed
limited: theoretical hull speed is 6.2 kn, and reaching it would take
about 30 kW. The curve is brutal past 4.5 kn — the last 0.3 kn costs
as much as the first 4.0.

The design conclusion: **cruise at 3–4 knots.** At 3.5 kn the boat has
153 NM of range on the battery alone, which covers a day's canal
passage or a coastal hop with reserve.

## 3. Solar-neutral cruising

This is the number that matters for a liveaboard.

| Condition | Solar/day | House load | Left for propulsion | Neutral speed |
|---|---|---|---|---|
| Good summer day | 24 kWh | 2.5 | 21.5 | **4.2 kn for 8 h** |
| Average spring/autumn | 12 kWh | 2.5 | 9.5 | 3.6 kn for 8 h |
| Overcast winter | 6 kWh | 2.5 | 3.5 | 2.7 kn for 8 h |

In summer the boat can move all day at 4.2 knots and still finish with
a fuller battery than it started. That, not the top speed, is the point
of a 4.4 kWp array on a 2.6 t boat.

**The mass rise costs almost nothing.** Going from the old 2 600 kg
assumption to the computed **3 582 kg** takes the maximum from 4.8 to
**4.7 kn** and the range at 3 kn from 240 to **233 NM**. At these
Froude numbers resistance is friction-dominated, and friction follows
*wetted surface*, which barely moved. Mass is a road and stability
problem on this boat, not a speed problem.

## 4. What is not modelled

- **Wind and sea.** Head wind and chop matter more than anything here
  for a 2.5 m-beam box with a 2.3 m air draft. Expect to lose a knot in
  a fresh breeze on the nose.
- **Appendage and interference drag** between the hull and the floats.
  The floats are close-coupled; their wave systems will interact, and
  it could go either way by a few percent.
- **Waterjet efficiency below 3 kn** is probably worse than the flat
  0.45 assumed. At displacement speeds a propeller would beat a jet
  comfortably — the jet is chosen for weed immunity and shallow draft,
  and it costs real efficiency.
- **Fouling.** A month on a mooring can add 30 % to friction.

## 5. Reproducing it

```sh
python3 docs/perf_model.py            # prints the tables above
```

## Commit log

2026-08-04 Initial design study: road-towable solar trimaran boat-home
    7.2 m Dutch-barge hull at max German road width (2.5 m). The
    stabilizer floats fold flush under the hull and carry six driven
    all-terrain wheels: the boat is its own trailer and slipway carriage.
    - Rigid segmented arms (shoulder pivot at the gunwale, 90-degree
    float roll at the wrist); caster-mounted wheels stay vertical on
    road, lie flat and covered in water
    - In-float electric-hydraulic wheel drive (48 V, orbital hub motors)
    - 3x 2 kW flush-intake waterjets: perforated side grids, protected
    impeller, weed-proof by low face velocity; differential steering
    - 12 flexible solar laminates (~5.2 kWp); bifacial balcony panels
    do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
    [Boat_2026-08-03.stl, ama.scad, arm.scad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]
2026-08-04 Rigid one-pivot hangar arms
    Arms are now fully welded static structures: the only rotating joint
    is the shoulder pin on the upper hull side; mid-arm joints become
    welded gussets and the arm-to-float connection is a static foot plate.
    Float roll is therefore locked 1:1 to arm swing, which fixes the swing
    at exactly 90 degrees. Shoulder repositioned to (1210, 760) so both
    poses land correctly: road pose unchanged (float flush under hull,
    wheels vertical), water pose at 4.72 m beam with identical immersion,
    grid submergence and balcony geometry. Launch/harbor now use the road
    configuration (drive in until afloat, then swing out).
    Docs updated (wheels.md kinematics, glossary shoulder/wrist).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
2026-08-04 Remove hydrofoil; jack-up harbor stance; winter garden; waterjets
    - Hydrofoil and all associated parts removed (Max: not going to use
    it). Five configurations remain: road, launch, harbor, cruise,
    anchor.
    - Propulsion reworked to flush-intake waterjets per Max's
    architecture: perforated side grids on the float midbodies and the
    submerged transom (vertical surfaces only — no bottom suction, no
    grid in front of a rotor), internal duct to an enclosed 2 kW pump,
    jet nozzle at the tail. Face velocity ~0.5 m/s; weed drifts past.
    - Jack-up harbor stance resolved and encoded: floats (3.1 t max
    buoyancy vs 2.0 t boat) cannot be submerged — folding the arms in
    deep water lifts the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
2026-08-04 Winter garden: full curved plexiglass envelope over the cabin
    Replaces the small bow blister Max rejected. One molded multi-bend
    piece: bottom edge at the sheer line where the hull starts, glass
    rising over both cabin sides to just under the roof-lid edge, wrapping
    the raked bow bubble down to the foredeck. Ruled loft over
    consistently-ordered frame sections gives the framed bent-panel look
    of the reference image; the solar roof lid caps the top opening so the
    pop-top still lifts. Glass footprint stays 30 mm inside the gunwale
    (road envelope unchanged).
2026-08-04 Winter garden: fuller, rounder glass profile
    Elliptical side curve with five bends per side and a gentle outward
    bulge; glass sides rise to the roof-lid edge with an open top over the
    cabin (pop-top unobstructed), closed rounded crown around the bow
    bubble over five frames. Ruled loft keeps the framed bent-panel
    construction.
2026-08-04 Exoskeleton frame, two-pose tow arch, closed foredeck
    Foredeck: deck plate now closes the top of the hull over its whole
    length; the sheer rising forward reads as a bow bulwark. No open
    cavity at the bow.
    Exoskeleton: external steel space frame takes every concentrated load
    off the hull skin — two full-length sheer rails, three cross-beams
    passing straight through the float-arm shoulder pins (float load goes
    rail-to-rail), posts, bow ring and stern ring. Float arms, solar
    balcony hinges, tow arch and fenders all mount to the frame.
    Tow arch: one A-arch on transverse pivots at the stem, pin-locked in
    two poses like the float arms. Sea +55 deg: apex 495 mm proud of the
    stem as a collision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
2026-08-04 Frame moved strictly outside: ladder loop, no members in the cabin
    The cross-beams ran through the living volume at knee height. They are
    gone. Two constraints force the only workable layout and are now
    documented: at shoulder height just 73 mm of width remains outboard
    before the 2550 mm limit, and the folded floats fill the underside
    from x 300 to 6500 — so a transverse tie amidships can go neither
    through the boat, nor outboard, nor underneath.
    The frame is now a ladder loop in plan: two chassis rails at shoulder
    height half-buried in the topsides (they read as a heavy rubbing wale,
    outer edge 1227 mm), two sheer rails on the side-deck strip outside
    the cabin wall, external straps betw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
2026-08-04 Tow moved to the stern; add self-recovery winch and anchor
    The boat now tows stern-first. The arch lives on the transom: raised
    at sea it is a gantry (anchor sheave, winch fairlead, nav-light post,
    davit points); swung down-aft with the tongue extended it is the
    drawbar, coupling 445 mm above ground, 1894 mm aft of the transom.
    Consequence handled: a stern coupling reversed the balance and gave
    -123 kg tongue load (lifting the hitch). The wheel group moved 573 mm
    forward to world x 1873/3573/5273, restoring +100 kg down on the ball
    — now asserted in checks() at 60-130 kg.
    The bow keeps a fixed external stem band from the frame as collision
    protection, so the rounded stem and the winter g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
2026-08-04 Aft entry: sunken cockpit, storm door, rain porch, ladder, AC, lockers
    The cabin is only 1000 mm above deck, so a full-height door is
    geometrically impossible (a 1900 mm door needs the cockpit floor below
    the waterline). Built as a proper companionway instead:
    - Sunken self-draining footwell, floor 360 mm above the waterline with
    transom scuppers, formed as a watertight tub let into the deck
    - Gasketed door with four dogs on a 180 mm storm sill, 700 x 1300 mm
    - Fixed porch roof over the whole cockpit, top flush with the roof
    terrace so it doubles as terrace floor; flashing seals it to the
    cabin wall
    - Ship's ladder (54 deg, 7 nosed treads, stringers, handrails both
    sides returning a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
2026-08-04 Ladder: single outboard handrail that folds flat when not needed
    Replaces the pair of fixed rails. One rail on the outboard (port) side
    only: raised when the pop-top terrace is in use, with posts at both
    ends and a return that continues as a terrace grab rail; folded flat
    onto the stringer in road, harbour and cruise trim so it takes no
    space. The inboard side needs none — it faces the cabin wall and the
    footwell drop beside it is only 530 mm.
2026-08-04 Aft entry reworked: deeper well, no posts, tighter ladder
    1. Ladder steeper and against the wall: 67 deg in 420 mm of run
    instead of 54 deg in 720. Alternating treads (eight, swapping
    sides) make that angle walkable and free most of the aft deck.
    2. Porch posts removed. The roof is cantilevered off the cabin wall on
    two diagonal tubes — nobody walks on it, so posts were only
    clutter.
    3. Cockpit floor lowered 620 -> 400 mm. Clear height at the door goes
    1480 -> 1700 mm (no more ducking), and the bulwark round the well
    grows to 750 mm, which is the barrier that stops someone stepping
    off into the water. Still 140 mm above the waterline, so it
    gravity-drains. Door now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
2026-08-04 Fix: boarding-gate hardware was breaking the road width limit
    The gate threshold plate reached y 1330 where the hull deck edge is
    only 1166-1231, so it stood up to 99 mm proud of the hull on each
    side: road width 2660 mm against a 2550 limit. checks() never caught
    it because road_width only looked at the hull, wheels, floats and the
    folded balcony.
    Threshold plate pulled inside the hull (y 1180) and the boarding grab
    post moved from y 1230 to 1150. Both are now included in the
    road_width computation so this class of error cannot recur.
    Also added fold_open / fold_closed renders that verify the aft passage
    is part of the folding solar panel: with the panel folded it stands
    vertical along it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
2026-08-04 Remove stray brace ends hanging outside the passage
    The under-deck balcony braces ran a fixed y-span, but over the narrow
    passage the plate is only 540 mm wide — so 540 mm of every aft brace
    hung in open air. Braces are now clipped to the plate outline: the
    wide deck section and the passage each get their own span.
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2026-08-04 Move the winch onto the centreline with the anchor
    An off-centre winch pulls with a yaw bias; on a slipway that fights the
    wheels exactly when grip is already marginal. The drum now sits on a
    stern-tie bracket at (-70, 0, 1310), athwartships, directly above the
    anchor roller at (-140, 0, 1150), so the rode leads dead aft along the
    keel line. Body sized 300 x 420 to clear the gantry legs at y +-950.
    checks() asserts both fittings within 30 mm of the centreline, the drum
    forward of the roller, and the body clear of the legs.
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2026-08-04 Replace the pop-top with a walk-on glass sun deck
    The scissor lift is deleted. Max judged it weak for rough sea and wind,
    and rechecking the mechanics agreed: the force at a scissor foot is
    W/tan(theta), not W/(2 tan theta) as first specced, so the real breakout
    was 11.4 kN per corner and not 3.6. Every fix traded lid thickness or
    added fatigue parts, and four salt-exposed mechanisms still had to hold
    a 7.7 kN gale uplift.
    The roof is now fixed structure: flexible laminates bonded on the 200 mm
    roof sandwich, a ventilated 60 mm air box, an alu grid, and 8 walk-on
    panes of 1200 x 1050 in 6+6 heat-strengthened laminated glass. People
    walk on the glass and the panels underneath can never be to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
2026-08-04 Walkable solar balconies with standard framed modules
    The side balconies now carry standard aluminium-framed PV modules -
    standardised, cheap, replaceable anywhere - with a walkway beside them.
    The roof's trick does not transfer: folded against the cabin the
    balcony assembly may be at most 75 mm thick before the 2550 road limit
    bites, and a walking surface over the panels needs 105 (module 35 + air
    gap 40 + tread 30). So the walkway sits BESIDE the panels in the same
    plane and the modules drop INTO the alu ladder frame rather than onto
    it - folded thickness 48 mm of the 75 available.
    Each balcony: 480 mm perforated anti-slip tread inboard, 3 standard
    1480 x 670 165 W modules outboard, alu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
2026-08-04 Fix roof panels running off the boat; standard 500 W modules
    Five laminates were laid at 1700 pitch from x 1040, so the last two ran
    to x 7920 - past the bow and hanging in space. The count was set
    without checking the layout against the field.
    Fixed at the root: deck_panel_xy() in params.py now computes the panel
    positions, build_terrace() draws exactly those, and checks() asserts
    every module lies inside the field in both axes. Geometry and checks
    can no longer disagree.
    Roof panels are now standard 500 W framed modules (1934 x 1134 x 30,
    24 kg) per Max, laid across the field - four fit, 2.00 kWp. They live
    inside the 60 mm air box under the glass, so they are replaceable at
    any solar sh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
2026-08-04 Remove the roof guardrail; handrail now follows the ladder
    Max: the stanchions and lifelines on the sun deck looked awful and are
    not wanted. The deck edge now carries the 80 mm toe rail and nothing
    else - the fall risk from 2.4 m is accepted deliberately, and that is
    written down in docs/roof.md rather than left implicit.
    The ladder handrail no longer projects above deck level. Following
    Max's reference photo, it is a second side rail running parallel to the
    stringer on three short standoffs, offset 220 mm, clipped so it
    terminates exactly at deck level - you grip it like a ladder rail while
    climbing and nothing sticks up on the deck.
    checks() now asserts a guardrail cannot reappear.
2026-08-04 Real datasheet dimensions; 400 W bifacial on the balconies
    Checked actual module datasheets instead of estimating. My 500 W figure
    was optimistic: real ones are 1961 x 1134 x 30 at 26-27 kg (Trina Vertex
    N, JA Solar JAM60D41), not 1934 x 24 kg. A 400 W is the 54-cell format,
    1722 x 1134 x 30, ~21 kg.
    Those 239 mm decide the balcony: three 400 W fit the 5300 mm run
    (3 x 1722 + gaps = 5246) where only two 500 W would go, so the smaller
    panel gives MORE power per side - 1.2 kW against 1.0.
    Balconies now carry 400 W BIFACIAL modules per Max. The rear face earns
    its keep there: folded up over the windows in road and harbour trim
    both faces see daylight, and deployed over the water the back pick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
2026-08-04 Add a fold-down upper bunk over the port settee
    Max wants one of the two single berths to be a bunk. A fixed two-tier
    bunk does not fit and the arithmetic is unambiguous: 1290 mm between
    the lower cushion (910) and the deckhead (2200), against the 1650 a
    real bunk wants (900 to sit under + 150 structure + 600 over the
    upper).
    So the upper berth folds. Hinged on the hull side, it lies flat at 2080
    under the deckhead by day - the settee keeps its full 1290 and the
    window is unobstructed - and drops to 1550 at night: 640 clear below,
    490 above, 1900 x 620. Lee cloth on the inboard edge, two fold-out
    treads at the aft end to climb up.
    Deployed it crosses the bottom third of the port window, wh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
2026-08-04 Add photo-reference renders; put them first in the PDF
    The standard captures are orthographic and let the interior show
    through the glass, so they read as cutaways rather than as a boat seen
    from outside.
    freecad/beauty_shots.py renders what an observer actually sees:
    perspective camera at natural eye heights (bow quarter, stern quarter,
    beam on, drone, low from the water), interior hidden, glazing closed to
    30% transparency, and a 90 m water/ground plane so the surface never
    ends inside the frame. 25 plates at 2800 x 1750.
    Camera is set through the Inventor camera STRING api - getCameraNode()
    needs pivy SWIG bindings that are not loaded in this headless-GUI run,
    which is what broke two ea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
2026-08-04 Drop the orthographic renders; perspective plates only
    Max: the old captures read as cut sections, not as a boat seen from
    outside. They are gone - from the README, from the PDF gallery, and
    from disk. What remains is the 25 perspective photo-reference plates
    plus the 2D drawings, which are drawings and look like it.
    PDF is 52 pages: perspective views inline in the configurations
    section, then all 25 plates, then the arrangement, interior and spec
    sheets.
    capture.py and interior_shots.py are no longer referenced by the
    documents; beauty_shots.py is the render path.
2026-08-05 Replace the winter garden with a front sky dome
    The old envelope wrapped the whole cabin and looked clunky; it also
    double-glazed over the picture windows that already light the saloon.
    The dome is now what Max asked for and nothing else: HALF a dome, cut
    flat by the deck. It springs off the sheer all the way round - the deck
    is its floor - opens aft into the saloon at the cabin's front opening
    (full 2400 roof height at the crown) and closes down onto the foredeck
    at x 7000, leaving 200 mm of solid bow. 1203 mm of head inside, so it
    is a place to sit with the view.
    600 flat glass triangles. A dome is doubly curved and flat glass cannot
    tile that with quads - the best quad layout tried stil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
2026-08-05 Front sky dome: 8 big hot-bent panes matching the cabin corners
    The dome now springs from the exact corners of the living-quarters box
    and closes onto the foredeck, half a dome cut flat by the deck.
    dome_section() blends an exact rectangle at the cabin face into an
    ellipse at the bow, so the aft arch is the cabin rectangle corner for
    corner. The glazing is one band of 8 large hot-bent panes instead of
    600 flat triangles: 9 seams, all running fore-and-aft, so no joint is
    horizontal and every seam sheds downhill. Tightest bend radius 1.6 m,
    gentler than a car windscreen.
    Renders regenerated for all five modes; docs/dome.md and README updated.
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2026-08-05 PDF: photo-realistic plates as the marketing opening
    Three impressions at the front - at anchor, under way, and on the
    autobahn behind the car - each full page with a headline and one line
    of copy, before any engineering. The title-page hero is the lake shot
    instead of the old orthographic render, which no longer exists.
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2026-08-06 Foam-core GRP structure, computed mass budget, and a builder's PDF
    Construction method moves to foam-core GRP sandwich, and the mass
    budget becomes a computed number instead of an assumption.
    freecad/laminate.py holds the schedule (cores, skins, fibre fraction,
    1.12 margin). freecad/areas.py measures the laminated area off the
    solids into areas.json - 102.8 m2 - and params.mass_budget() multiplies
    the two, so structural mass moves when the geometry or the schedule
    does. Structure comes out at 754 kg.
    checks() now asserts the things that were previously asserted by hand:
    - mass closure, which FAILS on purpose: 3282 kg empty, 3582 kg loaded
    against a 2000 kg design figure;
    - the 3500 kg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
2026-08-06 Weight study, cleaner cover, and no personal attributions in the docs
    Adds docs/weight.md: how to take the mass down without deleting a
    feature. The insight is that road mass and afloat mass are different
    numbers and only the road one is legally binding, so the heaviest
    consumables become removable - water and 20 kWh of the bank, -343 kg
    for the road - and six measured structural levers take another 259 kg
    out of the boat permanently: roof core 200 to 60 mm on two beams,
    foam-core joinery, walk-on glass only over the 6 m2 anyone walks on,
    6 mm dome glass, lighter float shell with local doublers, lighter
    bottom skin. Lands at 3 023 kg empty, 3 323 loaded, 2 680 on the road
    - back inside cat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
2026-08-06 Balconies become solar curtains on the roof corner
    The walkable solar balconies are gone: a ladder frame, a fold
    mechanism, legs down to the wheel boxes and about 149 kg a side, to
    make a side deck the cockpit and aft passage already made unnecessary.
    In their place the SAME Zendure 230 W panel as the roof rails, five a
    side in a light 20 mm aluminium frame, hinged on the corner where the
    cabin roof meets the side wall. Closed, they hang flat and cover the
    window band completely - that is the road pose, and at 2496 mm they sit
    inside the 2500 mm hull line so they no longer set the road width. At
    78 degrees they project 1129 mm out OVER the glass as an awning: full
    shade, view unobstructed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
2026-08-06 Detachable hangar: U-frame trailer, electric locks, dinghy mode
    The running gear is no longer welded into the hull. Two 55 x 200 alu
    spine beams run along the hull sides carrying the four arm shoulders,
    joined 320 mm aft of the transom by a bight that carries the drawbar.
    Coupled it is the trimaran as before; detached it is a 4.72 m catamaran
    with a motor in each float, 504 mm of freeboard with two aboard.
    The point is certification. With the gear welded in, the BOAT is an
    amphibious vehicle whose brakes no catalogue axle can supply. Detached,
    the hangar is a complete trailer and the boat is cargo - which is the
    most ordinary vehicle in Europe. homologation.md now opens by saying
    the pr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
2026-08-06 Elbowed arms: the inverted V, 2 m of clear water, and the drawbar
    Feedback: the floats must ride about 2 m off the hull for stability in
    waves, and the same arms must still fold them under the hull on the
    water - so a telescope is out, and a single-pivot arm cannot do it
    either: the sea stance is 2395 mm from the shoulder, the under-hull
    pose 990.
    Each arm now has a shoulder and an ELBOW, both 24 V worm slew drives.
    At sea the arm stands as an inverted V - elbow two metres above the
    water - with the float 2000 mm clear of the hull: righting moment goes
    from 31 to 54 kNm, righting SF from 4.2 to 7.2. To stow, both joints
    close together and the float sweeps in and under the hull. The folded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
2026-08-06 The carriage: original fixed arm on a sliding outrigger beam
    Reflection first: a rigid one-pivot arm cannot give both the 2 m sea
    stance and the under-hull stow. A rotation keeps the float at constant
    radius, so the pivot must be equidistant from both float positions -
    and inside the road envelope that caps the standoff at about 580 mm.
    The elbow fixed the geometry and ruined the machine.
    So the arm goes back to EXACTLY the original design - rigid, welded,
    radius 990, one 90 degree swing to flush under the hull - and the
    shoulder moves instead. Each station carries a crane-style outrigger
    beam sliding through a sleeve on the spine, driven by a 24 V leadscrew:
    sea beam out 1492 m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
2026-08-07 Fix view.sh: the model was never building on launch
    Two faults. FreeCAD does not set __name__ to '__main__' for scripts
    passed on the command line - it uses the filename - so the import guard
    added for areas.py silently disabled build_boat's launcher: FreeCAD
    opened and nothing built. Direct launch is now detected from argv
    instead.
    And a FreeCAD killed mid-run leaves its single-instance socket at
    /tmp/FreeCAD, after which every later launch blocks forever handing off
    to a dead process. view.sh now clears the stale socket when no FreeCAD
    is running, and its usage text lists the real modes (deck, detached,
    alongside; foiling is long gone).
2026-08-07 The T-hull: nesting floats level with the hull, flip wheels in bays
    The hull becomes a T aft of the bow: the underwater body narrows to a
    1800 mm stem, the deck keeps the full beam, and the bow stays full
    width to the waterline for stability forward. The floats - now slim,
    6000 x 350 x 600 - nest in the two notches beside the stem at the SAME
    level, bottoms flush, so the docked boat is one clean barge body with
    the float noses protected behind 1.2 m of solid bow. Two tapered
    spike rails per side take the fork-style docking; the bayonet lock
    pins it.
    Campervan-style scissor extenders (24 V leadscrew, self-locking, two
    per side) push the floats 1.8 m out horizontally for the trimaran
    stance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
2026-08-07 Review pass on the T-hull gear: fixed drawbar, real scissors, honest bays
    Four fixes from design review:
    - The bight and drawbar are a FIXED small triangle at docked width.
    They belong to the road function; the extended floats leave them
    behind, and the A-frame no longer stretches with the stance.
    - The 180-deg flip could not physically clear the float in the old
    drawing. The swing now passes the float's OUTBOARD side - the only
    clear volume - with the curved arm bulging outboard, and the bays
    biased 25 mm outboard so the wheel swings in. The hull itself
    forces the operating sequence: docked, the T wing sits directly over
    the float, so wheels flip only while EXTENDED, then t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
